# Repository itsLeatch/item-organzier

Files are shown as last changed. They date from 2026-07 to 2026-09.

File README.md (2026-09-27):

# item-organizer

You have problems to find a good place to store small objects that might be useful in the future? Me too! That's why I was building item-organizer.\
Just scan your screws, cables ... with the mobile app and the grabber will handle all of the other stuff. It handles you an available bin over and remembers its position.\
You want to find it later on? Just open up the app again, use the search function and receive the item bin by the grabber!

# Pictures
## Grabber




## App

show functionality

## PCB

controllboard front


### Power
To power the PCB you will need 24V for the motors. In addition you have to power the esp32 through out the usb-c port to make the logic work :-)

# Page

new zine page

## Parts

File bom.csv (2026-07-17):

Name | Link | amount | Note | Total price in €
Aluminium B-Type 20x20x350mm Extrusion | https://www.motedis.com/en/Profile-20x20-B-type-slot-6?added_to_cart=1&show_cart=1 | 4 |  | 6,1
Aluminium B-Type 20x20x650mm Extrusion | https://www.motedis.com/en/Profile-20x20-B-type-slot-6?added_to_cart=1&show_cart=1 | 4 |  | 11,32
Aluminium B-Type 20x20x450mm Extrusion | https://www.motedis.com/en/Profile-20x20-B-type-slot-6?added_to_cart=1&show_cart=1 | 4 |  | 7,84
Aluminium B-Type 20x20x620mm Extrusion | https://www.motedis.com/en/Profile-20x20-B-type-slot-6?added_to_cart=1&show_cart=1 | 1 |  | 2,7
corner bracket | https://www.motedis.com/en/Steel-bracket-configurator | 4 |  | 3,34
drob in nut M5 | https://www.motedis.com/en/T-nut-B-type-slot-6-M5 | 48+4+6=58 |  | 9,3
mounting screw M5x8 | https://www.motedis.com/en/Screw-DIN-7380?show_cart=1&from_cart=1&products_id=1070 | 48 |  | 3,48
MNG12H x 500mm | https://de.aliexpress.com/item/1810493644.html?mp=1 | 1 |  | 18,64
MNG12H x 400mm | https://de.aliexpress.com/item/1810493644.html?mp=1 | 2 |  | 35,9
M3x8 | https://www.motedis.com/en/Screw-DIN-7380?added_to_cart=1&show_cart=1 | 26 |  | 0,86
M3 drop in nut | https://www.motedis.com/en/T-nut-B-type-slot-6-M3?added_to_cart=1&show_cart=1 | 26 |  | 4,32
belt 6mm heigh, 1,5m length | https://www.amazon.de/QitinDasen-Zahnriemen-Zahnriemenscheibe-Bohrung-Torsionsfeder-silber/dp/B07SHB3NBV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 | 2 | just cut it in half | 19,48
GT2 20T Idler | https://www.amazon.de/QitinDasen-Zahnriemen-Zahnriemenscheibe-Bohrung-Torsionsfeder-silber/dp/B07SHB3NBV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 + https://www.motedis.com/de/Fuehrungsrad-GT2-20-Zaehne-5mm-Bohrung-fuer-6mm-Riemen | 6 | !one is missing in packet | "" + 2,16
GT2 20T with motor mount | https://www.amazon.de/QitinDasen-Zahnriemen-Zahnriemenscheibe-Bohrung-Torsionsfeder-silber/dp/B07SHB3NBV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 | 2 |  | ""
Idler assembly | https://www.motedis.com/de/Fuehrungsrad-fuer-6mm-breiten-Zahnriemen | 2 |  | 5,61
M3x16 screw | https://www.motedis.com/en/Screw-DIN-7380?added_to_cart=1&show_cart=1 | 8+4=12 |  | 0,68
M5x30 screw | * | 4 |  | *
M5 Hex Nut | * | 4+10+5+1=20 |  | *
M3x10 screw | https://www.motedis.com/en/Screw-DIN-7380?added_to_cart=1&show_cart=1 | 8 |  | 0,61
M5x10 screw | * | 4+6=10 |  | *
M5x40 screw | * | 2 |  | *
M5x60 screw | * | 4 |  | *
PP rope 60cm | * | 1 |  | *
M4 Nut | * | 4 |  | *
M4x16 screw | * | 4+4=8 |  | *
M2x12 screw | https://de.aliexpress.com/item/4000373283188.html | 4 |  | 2
Nema17 Motor | https://www.amazon.de/STEPPERONLINE-Schrittmotor-55Ncm-Meter-3D-Drucker/dp/B0B93HTR87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 | 2 |  | 25,98
Nema8 Motor | https://de.aliexpress.com/item/1005006701631058.html?mp=1 | 1 |  | 13
SG90 Microservo | have one at home | 1 |  | 0
cables | https://de.aliexpress.com/item/1005008857648878.html |  |  | 5,25
microswitch | https://www.amazon.de/DAOKAI-Endschalter-Scharnier-gerader-Momentschalter/dp/B09WVMRD5V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 | 1 |  | 4,89
microswitch cables |  |  |  | I have some at home
esp32 | https://www.amazon.de/WROOM-1-N16R8-ESP32-S3-DevKitC-1-Entwicklungsboards-Bluetooth-kompatibel/dp/B0FYFF8CB2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 |  |  | 9
24V Powersupply | https://www.amazon.de/Universal-Leistungstreiber-Steckeradaptern-Wechselrichter-Transformator-DC24V-1A/dp/B09KNC77W1 |  |  | 8,39
PCB |  |  |  | 9,9
TMC2208 | https://www.amazon.de/DollaTek-Schrittmotortreiber-3D-Drucker-Motherboard-K%C3%BChlk%C3%B6rper-Schraubendreher/dp/B081JNK7VQ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 |  |  | 16
M5x25mm | * | 4 |  | *
M5x35mm | * | 1+1=2 |  | *
PLA 1kg | https://www.amazon.de/eSUN-Filament-Geschwindigkeit-Ma%C3%9Fgenauigkeit-Hellgrau/dp/B0CR1CLQTJ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 | 1 |  | 10,82
loom bands to hold pla "nails" | (have mine at home) | ? | you can use theme to fix the nails, if they rotate and fall off | 0
shipping and taxes motedis |  |  |  | 22,65
Note: The * stands for my local shop, where the prices orient on weight. It's hard to tell how much the screws are weighting in toal! |  |  |  | 10
Total Price in Euro |  |  |  | 270,21
Total Price in Dollar |  |  |  | 308,0394

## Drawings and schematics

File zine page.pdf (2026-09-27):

# Item Organizer

## Do you have trouble finding a good place to

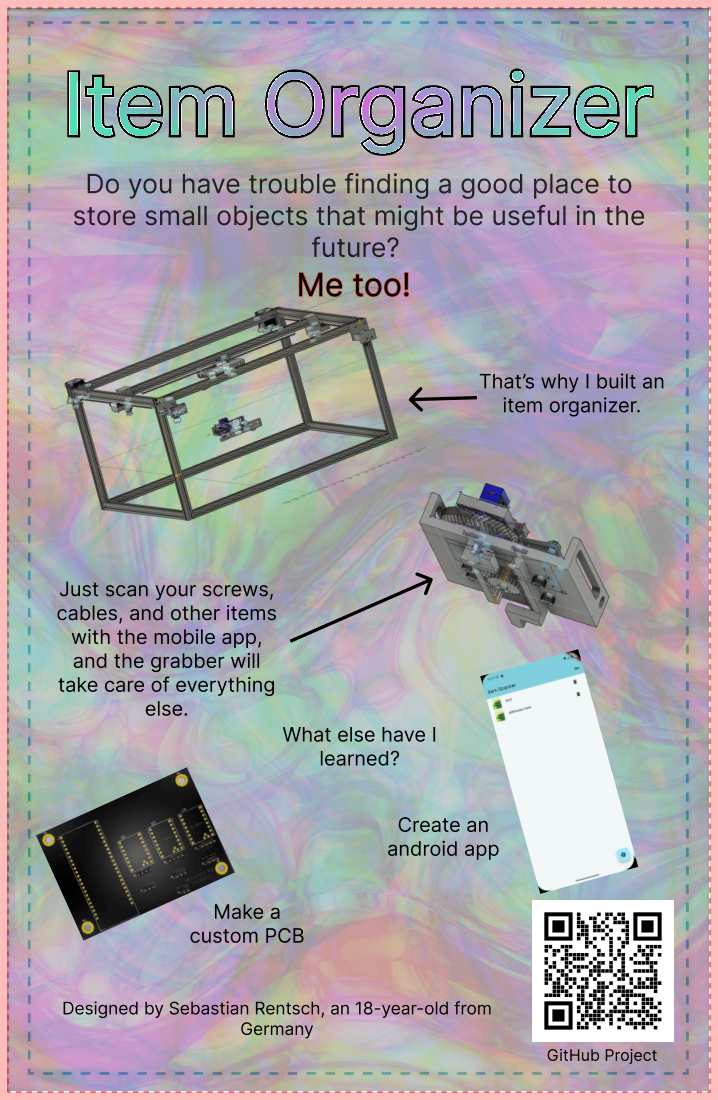
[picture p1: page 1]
future?; Me too!; item organizer.; else.; learned?; Create an; android app; Make a; custom PCB; Germany; GitHub Project

store small objects that might be useful in the

That’s why I built an

Just scan your screws,
cables, and other items
with the mobile app,

and the grabber will

take care of everything

What else have I

Designed by Sebastian Rentsch, an 18-year-old from

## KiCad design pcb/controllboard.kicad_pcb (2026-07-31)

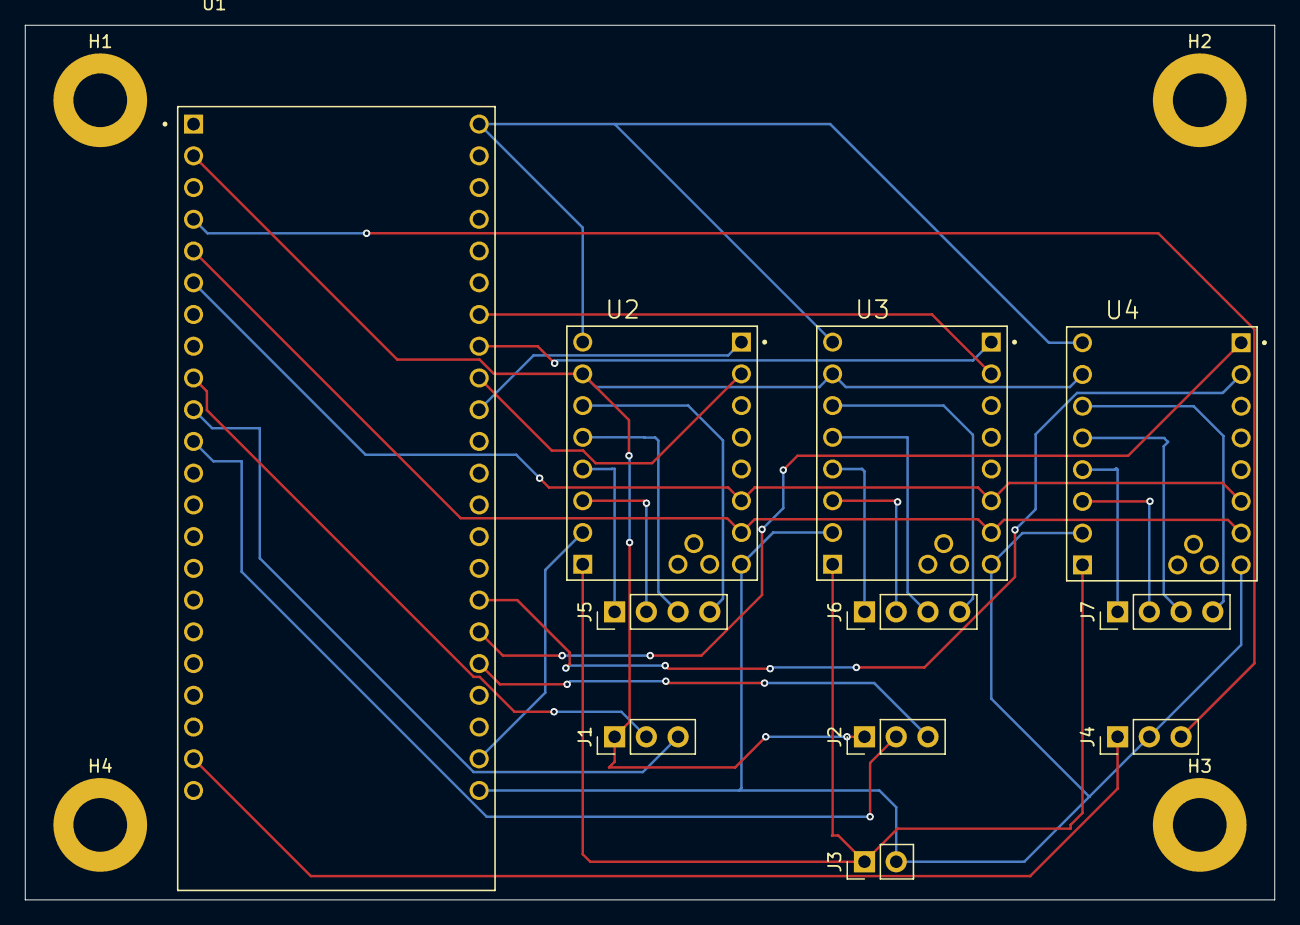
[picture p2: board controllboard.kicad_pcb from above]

Board: 2 copper layers, 100.0 x 70.0 mm, 15 parts (0 on the bottom side), 29 nets.

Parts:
H1, H2, H3, H4: MountingHole; MountingHole_4.3mm_M4_DIN965_Pad
J1: endstop X; PinHeader_1x03_P2.54mm_Vertical
J2: endstop Y; PinHeader_1x03_P2.54mm_Vertical
J3: 24V Power; PinHeader_1x02_P2.54mm_Vertical
J4: Servo Motor; PinHeader_1x03_P2.54mm_Vertical
J5: X Motor; PinHeader_1x04_P2.54mm_Vertical
J6: Y Motor; PinHeader_1x04_P2.54mm_Vertical
J7: lift Motor; PinHeader_1x04_P2.54mm_Vertical
U1: ESP32-S3-DEVKITC-1-N16R8V; XCVR_ESP32-S3-DEVKITC-1-N16R8V
U2: X Motor; MODULE_TMC2208_SILENTSTEPSTICK
U3: Y Motor; MODULE_TMC2208_SILENTSTEPSTICK
U4: lift Motor; MODULE_TMC2208_SILENTSTEPSTICK

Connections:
3V3: J1.1, J2.1, U1.J1_1 (3V3), U1.J1_2 (3V3), U2.JP2_7 (VIO), U3.JP2_7 (VIO), U4.JP2_7 (VIO)
GND: J3.2, J4.2, U1.J1_22 (GND), U1.J3_1 (GND), U1.J3_21 (GND), U1.J3_22 (GND), U2.JP1_8 (EN), U2.JP2_2 (GND), U2.JP2_8 (GND), U3.JP1_8 (EN), U3.JP2_2 (GND), U3.JP2_8 (GND), U4.JP1_8 (EN), U4.JP2_2 (GND), U4.JP2_8 (GND)
unnamed: J1.2, U1.J1_9 (GPIO16)
unnamed: J1.3, U1.J1_10 (GPIO17)
unnamed: J2.2, U1.J1_11 (GPIO18)
unnamed: J2.3, U1.J3_18 (GPIO21)
unnamed: J3.1, U2.JP2_1 (VM), U3.JP2_1 (VM), U4.JP2_1 (VM)
unnamed: J4.1, U1.J1_21 (5V0)
unnamed: J4.3, U1.J1_4 (GPIO4)
unnamed: J5.1, U2.JP2_4 (OA1)
unnamed: J5.2, U2.JP2_3 (OA2)
unnamed: J5.3, U2.JP2_5 (OB1)
unnamed: J5.4, U2.JP2_6 (OB2)
unnamed: J6.1, U3.JP2_4 (OA1)
unnamed: J6.2, U3.JP2_3 (OA2)
unnamed: J6.3, U3.JP2_5 (OB1)
unnamed: J6.4, U3.JP2_6 (OB2)
unnamed: J7.1, U4.JP2_4 (OA1)
unnamed: J7.2, U4.JP2_3 (OA2)
unnamed: J7.3, U4.JP2_5 (OB1)
unnamed: J7.4, U4.JP2_6 (OB2)
unnamed: U1.J1_5 (GPIO5), U2.JP1_7 (MS1), U3.JP1_7 (MS1), U4.JP1_7 (MS1)
unnamed: U1.J1_6 (GPIO6), U2.JP1_6 (MS2), U3.JP1_6 (MS2), U4.JP1_6 (MS2)
unnamed: U1.J3_10 (GPIO38), U2.JP1_1 (DIR)
unnamed: U1.J3_17 (GPIO47), U4.JP1_1 (DIR)
unnamed: U1.J3_16 (GPIO48), U4.JP1_2 (STEP)
unnamed: U1.J3_9 (MTCK/GPIO39), U2.JP1_2 (STEP)
unnamed: U1.J3_7 (MTDI/GPIO41), U3.JP1_2 (STEP)
unnamed: U1.J3_8 (MTDO/GPIO40), U3.JP1_1 (DIR)

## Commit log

2026-07-17 add most relevant files
    [controllboard.kicad_pcb, controllboard.kicad_sch]
2026-07-17 add bom
    [bom.csv]
2026-07-17 new frame page
2026-07-19 added gerber files
    [controllboard-B_Cu.gbr, controllboard-B_Mask.gbr, controllboard-B_Paste.gbr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]
2026-07-31 added drill files
    [controllboard-B_Cu.gbl, controllboard-B_Cu.gbr, controllboard-B_Mask.gbs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]
2026-09-25 rewrite readme + add pcb image
2026-09-27 Update README with PCB power requirements + PCB mounting image
    Added power requirements for the PCB.
2026-09-27 update zine page + new cad files
